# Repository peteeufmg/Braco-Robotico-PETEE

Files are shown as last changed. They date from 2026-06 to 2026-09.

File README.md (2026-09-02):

# Braço Robótico — PETEE UFMG

Projeto de braço robótico desenvolvido originalmente na disciplina de **Laboratório de Circuitos Elétricos 1** e doado ao grupo **PETEE (Programa de Educação Tutorial da Engenharia Elétrica) da UFMG**. Utilizado em atividades de extensão como a **Engenharia na Escola (ENE)** e a **Mostra de Profissões da UFMG** para demonstrar conceitos básicos de robótica e programação.

Inspirado no projeto [FoamArmDS da EasyDS](https://www.youtube.com/watch?v=vVOyWQZ25M8).

---

## Visão Geral da Arquitetura

O sistema é composto por dois elementos que se comunicam sem fio:

```
┌─────────────────────────────┐          ┌──────────────────────────────────┐
│         CELULAR (App)       │          │          BRAÇO ROBÓTICO          │
│                             │          │                                  │
│  Giroscópio + Acelerômetro  │          │  ESP32                           │
│  Slider de garra            │──────────│    ├── Servo 1 (Base - MG996R)   │
│  Botão: Sincronizar         │  Wi-Fi   │    ├── Servo 2 (Ombro - MG996R)  │
│  Botão: Gravar Posição      │  (UDP)   │    ├── Servo 3 (Cotovelo - SG92R)│
│  Botão: Reproduzir          │          │    ├── Servo 4 (Punho V - SG92R) │
│                             │          │    ├── Servo 5 (Punho R - SG92R) │
│  ► Todos os cálculos de     │          │    └── Servo 6 (Garra - SG92R)   │
│    posição e interpolação   │          │                                  │
│    são feitos aqui e        │          │  ► Executa as instruções         │
│    repassados ao ESP32      │          │    recebidas                     │
└─────────────────────────────┘          └──────────────────────────────────┘
```

**Princípio central:** O celular é o "cérebro" — ele lê os sensores, calcula as posições e envia apenas as instruções finais ao ESP32. O ESP32 atua como um executor, movendo os servos conforme os comandos recebidos. Isso simplifica o firmware e permite que toda a lógica de controle seja atualizada pelo app, sem regravar o hardware. A comunicação via **UDP** foi escolhida para garantir baixíssima latência e compatibilidade perfeita com atualizações OTA (Over-The-Air) do ESP32.

---

## Funcionalidades

### Modo Sincronia
- Ao ativar, o app passa a ler o **giroscópio e acelerômetro** do celular continuamente.
- O app mapeia o deslocamento angular do celular (roll, pitch, yaw) para os ângulos dos servos correspondentes do braço.
- Os ângulos calculados são enviados em **fluxo contínuo (UDP)** ao ESP32, que os executa em tempo real — o braço espelha o movimento do celular.
- Um **slider** na tela controla independentemente o ângulo de fechamento da garra (Servo 6).

### Modo Gravação
- Com o braço em qualquer posição (inclusive em sincronia), o usuário pressiona **"Gravar Posição"** no app.
- O app captura o estado atual dos 6 ângulos e os armazena localmente em uma lista ordenada.
- Podem ser gravadas múltiplas posições em sequência, formando uma "coreografia".

### Modo Reprodução
- O app percorre a lista de posições gravadas em loop.
- A **transição entre uma posição e a próxima é calculada pelo app** (interpolação), que envia o fluxo de ângulos intermediários ao ESP32 — garantindo movimentos suaves, sem solavcos.
- O ESP32 executa cada instrução recebida sem precisar conhecer a lógica de transição.

---

## Estrutura do Repositório

```
Braco-Robotico-PETEE/
│
├── hardware/                          # Projeto físico embarcado
│   ├── firmware/                      # Projeto PlatformIO (ESP32)
│   │   └── src/
│   │       └── main.cpp               # Firmware principal
│   ├── electronics/                   # KiCad: esquemáticos e PCB
│   │   ├── symbols/                   # Símbolos customizados
│   │   ├── footprints/                # Footprints customizados
│   │   └── datasheets/                # PDFs dos datasheets dos componentes
│   └── mechanical/                    # Modelagem 3D e impressão
│       ├── freecad/                   # Arquivos fonte .FCStd
│       └── stl/                       # Arquivos exportados para impressão
│
├── app/                               # Aplicativo mobile de controle (em desenvolvimento)
│
├── docs/                              # Documentação e relatórios
│   └── Relatorio_BracoRobotico.pdf    # Relatório da versão original
│
└── README.md
```

---

## Hardware

### Componentes

| Quantidade | Componente | Observação |
|---|---|---|
| 4× | Servo Motor SG92R 180° | Para as juntas mais leves (Cotovelo, Punhos e Garra) |
| 2× | Servo Motor MG996R 180° | Para as juntas pesadas (Base e Ombro), garantindo alto torque e estabilidade |
| 1× | ESP32 (30 pinos) | Microcontrolador principal (Wi-Fi) |
| 1× | Bateria LiPo 2S 7.4V 2200mAh 30C | Alta capacidade de descarga (66A contínuos), elimina risco de queda de tensão (brownout) |
| 1× | Módulo Buck Converter XL4015 | Rebaixador step-down de 5A |
| — | PCB customizada (KiCad) | Esquemático e layout em `hardware/electronics/` |

### Mapeamento de Pinos — ESP32

Foram escolhidos apenas pinos "100% seguros" (que não interferem no boot do ESP32) e agrupados fisicamente no mesmo lado da placa para facilitar o roteamento da PCB no KiCad.

| Pino ESP32 | Função |
|---|---|
| `GPIO 13` | Servo 1 — Base (MG996R) |
| `GPIO 14` | Servo 2 — Ombro (MG996R) |
| `GPIO 25` | Servo 3 — Cotovelo (SG92R) |
| `GPIO 26` | Servo 4 — Punho Vertical (SG92R) |
| `GPIO 27` | Servo 5 — Punho Rotacional (SG92R) |
| `GPIO 33` | Servo 6 — Garra (SG92R) |

### Alimentação (Arquitetura Híbrida)

O sistema pode exigir picos de corrente de até **8 Amperes** se todos os servos sofrerem carga simultaneamente. Para não sobrecarregar o Buck Converter de 5A (XL4015), a alimentação foi dividida na PCB:
1. **Os 2× MG996R** são alimentados **diretamente** pela bateria LiPo 2S (7.4V nominal), operando no seu torque máximo.
2. **O Buck Converter XL4015** rebaixa os 7.4V para **5V** para alimentar apenas o **ESP32** (pelo pino VIN) e os **4× SG92R**.

---

## Mecânica

Modelagem 3D desenvolvida no **FreeCAD**. As peças são projetadas para impressão em **PLA ou PETG**.

### Referências para Modelagem

| Parâmetro | Valor |
|---|---|
| Dimensões do SG92R | 22,8 × 12,5 × 22,7 mm (Eixo Ø 4,7 mm) |
| Dimensões do MG996R | 40,7 × 19,7 × 42,9 mm |
| Tolerância recomendada nos encaixes | 0,2 mm |
| Espessura mínima das paredes | 2 mm nas juntas |
| Fixação | Parafusos M2/M3 |

### Arquivos
- Fonte: `hardware/mechanical/freecad/`
- Exportados para impressão: `hardware/mechanical/stl/`

---

## Firmware

O firmware é desenvolvido com **PlatformIO** (VS Code) para o **ESP32**.
O firmware tem responsabilidade única: **receber pacotes UDP de ângulos via Wi-Fi e mover os servos correspondentes**.

### Dependências

| Biblioteca | Uso |
|---|---|
| `ESP32Servo` | Controle de servos via canais PWM por hardware do ESP32 |
| `WiFi.h` & `WiFiUdp.h` | Conexão de rede e recepção de pacotes (AP ou Cliente) |

### Formato do Pacote Recebido (Proposta Inicial)

Exemplo de pacote UDP (String):
```
S1:090,S2:045,S3:120,S4:090,S5:000,S6:030\n
```
Onde cada valor é o ângulo alvo (0–180°) do servo correspondente.

### Como Compilar e Gravar

1. Instale o [VS Code](https://code.visualstudio.com/) com a extensão **PlatformIO**.
2. Abra a pasta `hardware/firmware/` no VS Code.
3. Conecte o ESP32 via USB.
4. Clique em **Upload** (ícone de seta) na barra inferior do PlatformIO.

---

## App — Interface de Controle

O aplicativo mobile é o "cérebro" do sistema. Como é considerado um projeto de natureza transitória (focado na execução rápida e prova de conceito), a plataforma escolhida prioriza o desenvolvimento rápido e simples (ex: **React Native com Expo** ou até ferramentas low-code para prototipagem rápida).

Responsabilidades do App:
- Ler o **giroscópio e acelerômetro** do celular.
- Calcular **interpolações de movimento** entre posições gravadas.
- Enviar as instruções via **Wi-Fi (UDP)** ao ESP32.
- Gerenciar a lista de posições gravadas localmente.

---

## Pontos de Atenção para Manutenção

| Item | Descrição |
|---|---|
| **Alimentação** | Verificar carga da bateria antes de apresentações. Tensão insuficiente causa comportamento imprevisível nos servos (brownout no ESP32). A LiPo não deve baixar de 3.3V por célula. |
| **Estrutura física** | Inspecionar encaixes das peças 3D e fixação dos servos antes de cada uso. |
| **Servos** | Calibrar a posição zero de cada servo (com um Servo Tester) antes de montar as peças mecânicas. Um servo descalibrado pode forçar e quebrar as peças impressas. |

---

## Equipe

**Projeto original:** Lorran Pires Venetillo Dutra, Michael Cassemiro Oliveira, Vítor Gabriel Reis Caitité, Willian Braga da Silva.

**Versão atual (PETEE):** Hugo e equipe do PETEE.

Mantido pelo grupo **PETEE — UFMG** | [petee.cpdee.ufmg.br](http://www.petee.cpdee.ufmg.br/)

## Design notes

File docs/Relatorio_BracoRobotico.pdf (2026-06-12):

Programa de Educação Tutorial da Engenharia Elétrica Universidade Federal de Minas Gerais

PETEE | Relatório

# Relatório de Atividade

## Braço Robótico

Lorran Pires Venetillo Dutra, Michael Cassemiro Oliveira, Vítor

Gabriel Reis Caitité, Willian Braga da Silva

### Petianos responsáveis pelo projeto, em ordem alfabética

### Resumo

O projeto desenvolvido é inspirado no braço robótico FoamArmDS desenvolvido pela EasyDS. O Braço Robótico possuiu sua estrutura construída com spumaPaper (material facilmente modelado), além de servo motores, placa de circuito impresso e um microcontrolador Arduino. É um projeto que tem como objetivo transmitir conceitos básicos de robótica.

Conteúdo

I Introdução | 1
II Materiais e Métodos | 2
III Resultados | 12
IV Discussão | 13
I. Introdução

O Braço Robótico foi um projeto desenvolvido na disciplina de Laborátorio de Circuitos Elétricos 1. Ao final da disciplina os alunos envolvidos com o projeto decidiram que o projeto seria doado ao grupo PETEE. No grupo o Braço Robótico é utilizado principlamente nas atividades de extensão, como a Engenharia na Escola (ENE) e Mostra de Profissões

da UFMG. Dessa forma, por meio do protótipo é possível explicar, ao público interessado, conceitos básicos de robótica e programação.

http://www.petee.cpdee.ufmg.br/ | 1

### II MATERIAIS E MÉTODOS

II. Materiais e Métodos

### Materias para a construção do Braço Robótico:

### - 6x Micro Servo 9g

### - 4x Chave Tactil 12x12x4,3mm

### - 6x Potenciometro Linear Mini 1K

### - 5x Led Vermelho Difuso 3mm

### - 5x Led Amarelo Difuso 3mm

### - 5x Led Verde Difuso 3mm

### - 2xPlaca CI De Fenolite Virgem 10x20

### - Jack J4 DC-002

### - Jack J4 DC-005 P/ Placa 2,1mm X 5,5mm

### - Jack J4 DC-005 P/ Placa 2,5mm X 5,5mm

### - 4x Chave Tactil 12x12x4,3mm 4 Terminais

### - Spumapaper

### - 2x Chave Tactil 12x12x12mm 4 Terminais

### - Knob AD-110 Azul Para Eixo Estriado

### - Knob AD-110 Verde Para Eixo Estriado

### - Knob AD-110 Branco Para Eixo Estriado

### - Arduino Uno

### - suporte para 4 pilhas

### - pilhas de 1.2V cada

### - jumpers macho/fêmea

A primeira etapa da construção do Braço Robótico foi a realização de testes no protoboard. Para isso foi realizado a montagem da Figura 1 e o código foi carregado no Arduino Uno.

2 | Universidade Federal de Minas Gerais

## Relatório de Atividade

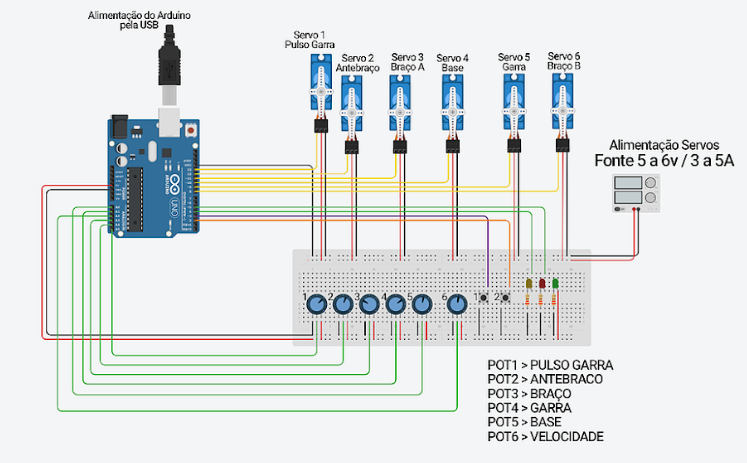
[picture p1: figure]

Figura 1: Diagrama de montagem no protoboard

### Código

\begin{ArduinoSketchBox}{title}

#include <VarSpeedServo.h>

#include <EEPROM.h>

#define espacoMemoria 199

#define tempoPausaEntreMovimentos 500 //configura o tempo de pausa entre cada movimento

#define pinServo1 | 13

#define pinServo2 | 12

#define pinServo3 | 11

#define pinServo4 | 10

#define pinServo5 | 9

#define pinServo6 | 8

#define pinBotao1 | 3

#define pinBotao2 | 2

#define pinLedA | 5

#define pinLedB | 4

#define pinPot1 | A5

#define pinPot2 | A4

#define pinPot3 | A3

#define pinPot4 | A0

#define pinPot5 | A1

PETEE | 3

#define pinPot6 | A2

VarSpeedServo servo1;
VarSpeedServo servo2;
VarSpeedServo servo3;
VarSpeedServo servo4;
VarSpeedServo servo5;
VarSpeedServo servo6;

byte pinBotao1Modo();
bool pinBotao2Retencao();
void pinLedAPisca(bool reset = false);
void setMemoria(byte posicao, byte servo, byte valor); byte readMemoria(byte posicao, byte servo);

int ultMemoria;

void setup() {
servo1.attach(pinServo1);
servo2.attach(pinServo2);
servo3.attach(pinServo3);
servo4.attach(pinServo4);
servo5.attach(pinServo5);
servo6.attach(pinServo6);

pinMode(pinLedA, OUTPUT);
pinMode(pinLedB, OUTPUT);

pinMode(pinBotao1, INPUT_PULLUP); pinMode(pinBotao2, INPUT_PULLUP);

ultMemoria = EEPROM.read(0);
}

void loop() {
static byte modo = 0;
static byte modoAnt;
static byte movimento = 0; static byte posMemoria = 0; static unsigned long delayPausa;

//Modo Normal
if (modo == 0) {
digitalWrite(pinLedA, LOW);

if (pinBotao2Retencao()) { digitalWrite(pinLedB, HIGH);

//executa um movimento
if (movimento == 0) {
byte velocidade = map(analogRead(pinPot6),0,1023,0,255); servo1.slowmove(readMemoria(posMemoria,0), velocidade); servo2.slowmove(readMemoria(posMemoria,1), velocidade); servo3.slowmove(readMemoria(posMemoria,2), velocidade); servo4.slowmove(readMemoria(posMemoria,3), velocidade);
servo5.slowmove(readMemoria(posMemoria,4), velocidade);
//servo6.slowmove(readMemoria(posMemoria,2), velocidade);
servo6.slowmove( map(readMemoria(posMemoria,2), 0, 179, 179, 0), velocidade); //Servo sincronizado inversamente ao Servo3 movimento = 1;
}

//aguarda término de um movimento para selecionar o próximo movimento if (movimento == 1) {
if ( (servo1.read() == readMemoria(posMemoria,0)) && (servo2.read() == readMemoria(posMemoria,1)) && (servo3.read() == readMemoria(posMemoria,2)) && (servo4.read() == readMemoria(posMemoria,3)) && (servo5.read() == readMemoria(posMemoria,4)) ) {

posMemoria++;
if (posMemoria > ultMemoria) { posMemoria = 0; }

delayPausa = millis();
movimento = 2;
}
}

//pausa entre movimentos
if (movimento == 2) {
if ((millis() - delayPausa) > tempoPausaEntreMovimentos) { movimento = 0;
}
}

} else {
digitalWrite(pinLedB, LOW);

if (pinBotao1Modo() == 2) {

modo = 1;
}
}
}

//Modo Gravação
if (modo == 1) {

if (modoAnt == 0) {
pinLedAPisca(true);
ultMemoria = -1;
EEPROM.write(0, ultMemoria); }

digitalWrite(pinLedB, LOW); pinLedAPisca();

if (pinBotao1Modo() == 2) { modo = 0;
}

servo1.write( map(analogRead(pinPot1),0,1023,0,179) ); servo2.write( map(analogRead(pinPot2),0,1023,0,179) ); servo3.write( map(analogRead(pinPot3),0,1023,0,179) ); servo4.write( map(analogRead(pinPot4),0,1023,0,179) ); servo5.write( map(analogRead(pinPot5),0,1023,0,179) ); //servo6.write( map(analogRead(pinPot3),0,1023,0,179) ); servo6.write( map(analogRead(pinPot3),0,1023,179,0) ); //Servo //sincronizado inversamente ao Servo3

if (pinBotao2Apertado()) {
ultMemoria++;
EEPROM.write(0, ultMemoria);
setMemoria(ultMemoria, 0, map(analogRead(pinPot1),0,1023,0,179)); setMemoria(ultMemoria, 1, map(analogRead(pinPot2),0,1023,0,179)); setMemoria(ultMemoria, 2, map(analogRead(pinPot3),0,1023,0,179)); setMemoria(ultMemoria, 3, map(analogRead(pinPot4),0,1023,0,179)); setMemoria(ultMemoria, 4, map(analogRead(pinPot5),0,1023,0,179));

digitalWrite(pinLedB, HIGH);
delay(250);
digitalWrite(pinLedB, LOW);

if ( ultMemoria == (espacoMemoria - 1)) {

modo = 0;
}
}
}

modoAnt = modo;
}

byte pinBotao1Modo() {
#define tempoDebounce 40 //(tempo para eliminar o efeito Bounce //EM MILISEGUNDOS)

#define tempoBotao 1500

bool estadoBotao;
static bool estadoBotaoAnt;
static byte estadoRet = 0;
static unsigned long delayBotao = 0;
static byte enviado = 0;

if ( (millis() - delayBotao) > tempoDebounce ) { estadoBotao = digitalRead(pinBotao1);
if (estadoRet == 0) {
if ( !estadoBotao && (estadoBotao != estadoBotaoAnt) ) { estadoRet = 1;
delayBotao = millis();
}
}

if (estadoRet == 1) {
if ( estadoBotao && (estadoBotao != estadoBotaoAnt) ) { estadoRet = 0;
delayBotao = millis();
}
}
estadoBotaoAnt = estadoBotao; }

if (estadoRet == 1) {
if ((millis() - delayBotao) > tempoBotao) { estadoRet = 2;
delayBotao = millis();
}
}

if (estadoRet == 2) {
enviado++;

if (enviado >= 2) {
estadoRet = 0;
delayBotao = millis();
enviado = 0;
}
}

return estadoRet;
}

bool pinBotao2Retencao() {
#define tempoDebounce 40 //(tempo para eliminar o efeito Bounce EM //MILISEGUNDOS)

bool estadoBotao;
static bool estadoBotaoAnt;
static bool estadoRet = false;
static unsigned long delayBotao = 0;

if ( (millis() - delayBotao) > tempoDebounce ) { estadoBotao = digitalRead(pinBotao2);
if ( !estadoBotao && (estadoBotao != estadoBotaoAnt) ) { estadoRet = !estadoRet;
delayBotao = millis();
}
if ( estadoBotao && (estadoBotao != estadoBotaoAnt) ) { delayBotao = millis();
}
estadoBotaoAnt = estadoBotao;
}

return estadoRet;
}

bool pinBotao2Apertado() {
#define tempoDebounce 40 //(tempo para eliminar o efeito Bounce EM MILISEGUNDOS)

bool estadoBotao;
static bool estadoBotaoAnt;
static bool estadoRet;
static unsigned long delayBotao = 0;

estadoRet = false;
if ( (millis() - delayBotao) > tempoDebounce ) { estadoBotao = digitalRead(pinBotao2);
if ( !estadoBotao && (estadoBotao != estadoBotaoAnt) ) { estadoRet = true;
delayBotao = millis();
}
if ( estadoBotao && (estadoBotao != estadoBotaoAnt) ) { delayBotao = millis();
}
estadoBotaoAnt = estadoBotao;
}

return estadoRet;
}

void pinLedAPisca(bool reset) { static unsigned long delayPisca = 0;

if (reset) {
delayPisca = millis();
} else {

if ((millis() - delayPisca) < 500) { digitalWrite(pinLedA, LOW);
} else {
digitalWrite(pinLedA, HIGH);
}

if ((millis() - delayPisca) >= 1000) { delayPisca = millis();
}
}
}

void setMemoria(byte posicao, byte servo, byte valor) { int posMem;

posMem = ((posicao * 5) + servo) + 1; EEPROM.write(posMem, valor);
}

byte readMemoria(byte posicao, byte servo) {

int posMem;

posMem = ((posicao * 5) + servo) + 1; return EEPROM.read(posMem);
}
\end{ArduinoSketchBox}

### Após a realizada a montagem da Figura 1 acima e verificado o correto funcionamento na protoboard, foi realizado o projeto da placa de circuito impresso no software Eagle e

montagem ( confecção e soldagem dos componentes), como mostra as figuras abaixo.

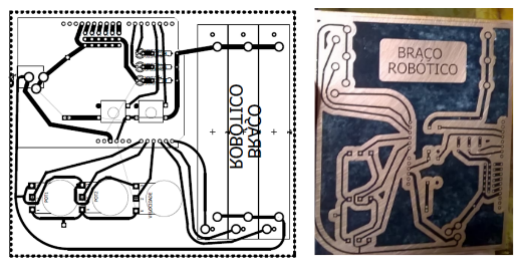
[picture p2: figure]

Figura 2: Esquemático de trilhas e placa de circuito impresso

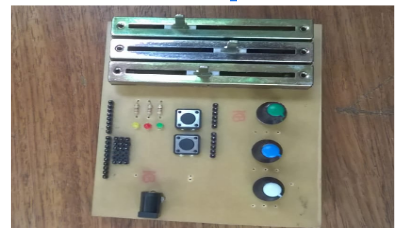
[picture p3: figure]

Figura 3: Placa finalizada

### Com a placa finalizada foram confeccionadas todas as peças de spumapaper necessárias pra

a estrutura do Braço Robótico. Na Figura 4 é ilustrado as peças confeccionadas e na Figura 5 é mostrado a estutura geral do Braço Robótico.

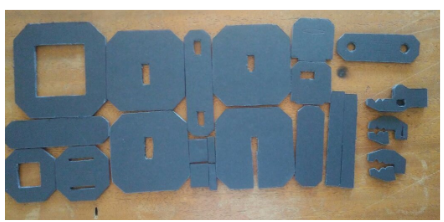
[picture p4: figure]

Figura 4: Peças confeccionadas

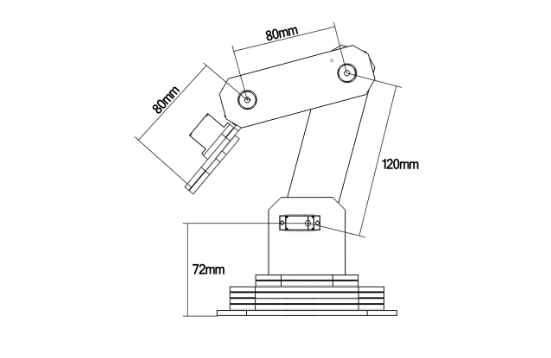
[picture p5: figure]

Figura 5: Estrutura geral do Braço Robótico

Funcionamento do Braço Robótico O Braço Robótico é alimentado por uma fonte de 5V (4 pilhas de 1.2V em série), o Led vermelho estará piscando e o verde acesso quando o projeto estiver em funcionamento. Existem dois modos de funcionamento, o modo manual e o modo de gravação. No modo manual os servos motores são todos controlados pelos potenciômetros (exceto o potenciômetro de knob verde) da placa de circuito impresso que está conectada com o Arduino Uno. No modo de gravação poderão ser gravados atá cinco movimentos do Braço Robótico. Para isso a cada posição de interesse é preciso apertar e

soltar o push button que está logo abaixo dos Leds, o Led amarelo irá piscar indicando que

a posição foi gravada. Após as gravações das posiçoes apertar-se e segura o push button mais distante dos Leds até que o Led vermelho pare de piscar e se apague, depois deve-se clicar no outro push button e o Braço Robótico passará a executar as posiçoes que foram gravadas e o Led amarelo acenderá. O potenciômetro de knob verde determina a velocidade

de execução dos movimentos que foram gravados no modo de gravação.

### III RESULTADOS

III. Resultados

O projeto apresentou resultados satisfatórios desde sua construção e cumpriu com as funções

que foram determinadas para ele. É capaz de executar movimentos em diferentes direções tanto de forma manual como de forma automática pelo modo de gravação. Alguns pontos do projeto que se deve ter uma atenção é a questão da alimentação, que para o correto funcionamento deve estar sempre em 5V, portanto problemas de bateria descarregadas podem acontecer com frequência. Além disso, o material e o encaixe dos servos não possuem muita qualidade, dessa forma pode acontecer de alguma das partes se soltarem ou até mesmo se danificarem. Por fim, o projeto apresenta bom funcionamento durante as apresentações e gera muito interesse do público. Na Figura 6 é apresentado o projeto

finalizado do Braço Robótico.

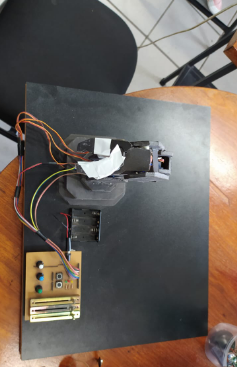
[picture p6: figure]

Figura 6: Braço Robótico

### REFERÊNCIAS

IV. Discussão

### O Braço Robótico não sofreu alteraões significativas desde a sua construção, resolver os

problemas de alimentação e de fragilidade citados anteriormente pode melhorar significati-

### vamente o protótipo. Além disso, tomando como base o modelo desenvolvido é possível

elaborar um braço robótico em maior escala, mais robusto e com maior grau de movimentos.

Referências

### <https://www.youtube.com/watch?v=vVOyWQZ25M8>

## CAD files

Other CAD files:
hardware/mechanical/freecad/Braco.FCStd

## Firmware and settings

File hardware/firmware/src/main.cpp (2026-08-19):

#include <Arduino.h>

// put function declarations here:
int myFunction(int, int);

void setup() {
  // put your setup code here, to run once:
  int result = myFunction(2, 3);
}

void loop() {
  // put your main code here, to run repeatedly:
}

// put function definitions here:
int myFunction(int x, int y) {
  return x + y;
}

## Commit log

2026-08-19 refactor: reestruturacao do repositorio com nomes padrao da industria
    - BackEnd/ renomeado para hardware/ (firmware, electronics, mechanical)
    - FrontEnd/ renomeado para app/
    - Relatorio_BracoRobotico.pdf movido para docs/
    - Novas pastas: electronics/symbols, electronics/datasheets, mechanical/freecad, mechanical/stl
    - README.md atualizado com nova estrutura e caminhos corrigidos
2026-08-19 refatoração: reorganização da estrutura do firmware e migração para PlatformIO
2026-09-02 chore: inicializa projetos base de eletrônica e mecânica
    - Adiciona arquivo .gitignore global.
    - Inicializa KiCad (electronics) e FreeCAD (mechanical).
    - Adiciona workspace do VS Code.
    [Braco.FCStd, electronics.kicad_pcb, electronics.kicad_sch]
